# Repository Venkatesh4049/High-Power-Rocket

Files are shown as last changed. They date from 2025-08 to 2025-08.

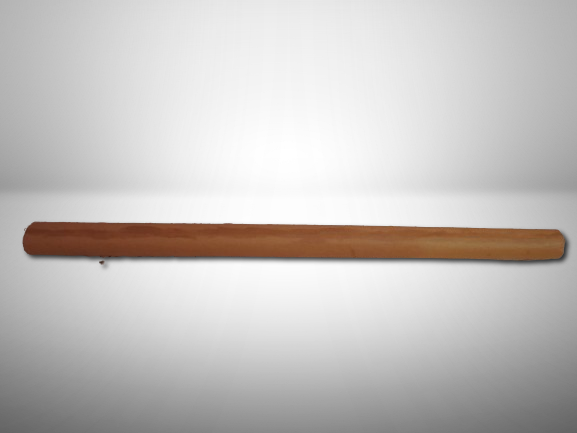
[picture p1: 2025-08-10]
Images/Bodytube.png

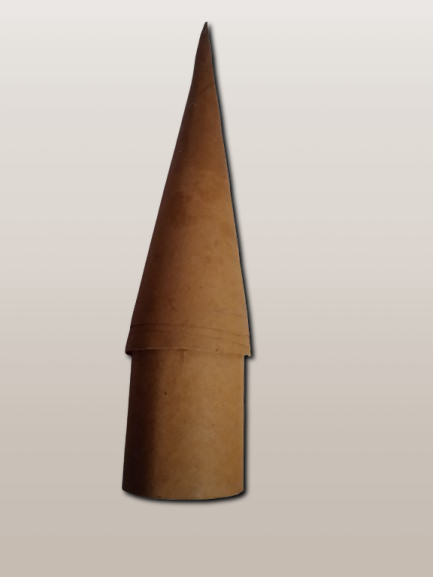
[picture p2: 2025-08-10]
Images/Nose side.png

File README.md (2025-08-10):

# High-Power Rocket Project

**Design and Development of a High-Power Rocket Using Composite Materials**

This repository contains the design, fabrication, and testing details of a student-built high-power rocket made from kraft-phenolic composite materials and powered by a potassium nitrate–glucose solid propellant. The project demonstrates that affordable, sustainable materials can achieve high-performance results in amateur rocketry.

## Features
- Kraft-phenolic composite body, fins, and nose cone for strength, thermal resistance, and low cost
- Custom solid propellant (KNO₃–glucose) with optimized grain geometry
- De Laval nozzle design for efficient thrust
- Parachute recovery system with ejection charge triggered at apogee
- Avionics bay with sensors, telemetry, and data logging
- Aerodynamic and propulsion simulations using OpenRocket and OpenMotor
- Static ground tests and subsystem validation

## Repository Structure
.
├── README.md                 # Project overview  
├── LICENSE                    # License file  
├── High_Power_Rocket.pdf      # Full project report  
├── CAD/                       # 3D models and drawings  
├── Simulations/               # OpenRocket (.ork) and OpenMotor files  
├── Fabrication/               # Build instructions, material specs  
├── Propulsion/                # Propellant design and nozzle calculations  
├── Recovery/                  # Parachute design, ejection system  
├── Electronics/               # Avionics schematics and firmware  
├── Testing/                   # Static tests, flight data  
└── docs/                      # Diagrams, additional documentation  

## Getting Started
1. Clone the repository:
   git clone https://github.com/Venkatesh4049/High-Power-Rocket.git
   cd High-Power-Rocket

2. Open `High_Power_Rocket.pdf` for the complete project documentation.

3. Use OpenRocket and OpenMotor to view simulation files in `/Simulations/`.

4. Explore CAD designs in `/CAD/` and build instructions in `/Fabrication/`.

## Safety & Legal Notice
This project is for educational purposes only.  
Follow all local regulations for propellant handling, motor building, and rocket launches.  
Always use approved testing and launch facilities with appropriate safety measures.

## License
Released under the MIT License. See `LICENSE` for details.

## Credits
Project by Venkatesh A M and team. See `High_Power_Rocket.pdf` for full acknowledgments.

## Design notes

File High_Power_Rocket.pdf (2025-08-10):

# DESIGN AND DEVELOPMENT OF A HIGH-POWER ROCKET USING COMPOSITE MATERIALS

### ME3811 - PROJECT WORK

### Submitted by

VENKATESHA RISHI A 910021114048
VENKATESH A M | 910021114049
SANJAY ROOPAN S | 910021114036
NISANTHALAL M J | 910021114029

### in partial fulfillment for the award of the degree of

# BACHELOR OF ENGINEERING

in

# MECHANICAL ENGINEERING

## ANNA UNIVERSITY, REGIONAL CAMPUS

## MADURAI - 625019

## ANNA UNIVERSITY: CHENNAI 600 025

### MAY 2025

# ANNA UNIVERSITY: CHENNAI - 600025

## BONAFIDE CERTIFICATE

Certified that this project report titled ”DESIGN AND DEVELOPMENT OF A HIGH-

POWER ROCKET USING COMPOSITE MATERIALS” is the bonafide work of VENKATESHA

RISHI A - 910021114048, VENKATESH A M - 910021114049, SANJAY ROOPAN S - 910021114036,

NISANTHALAL M J - 910021114029 who carried out the project under my supervision.

SIGNATURE | SIGNATURE
HEAD OF THE DEPARTMENT | PROJECT SUPERVISOR
Dr.S.Sudhakar | Mr.B.J Ashok Kumar
Assistant Professor | Teaching Fellow
Department of Mechanical Engineering | Department of Mechanical Engineering
Anna University Regional Campus | Anna University Regional Campus
Madurai - 625019 | Madurai - 625019

Submitted for the project viva-voice examination held on

Internal Examiner | External Examiner

i

# ABSTRACT

In a time where space exploration is often confined to billion-dollar agencies and high-end

facilities, this project represents a bold step towards democratizing rocketry through ingenuity, sus-

tainability, and resourcefulness. This study documents the complete design, fabrication, and testing

of a high-power rocket built using kraft paper-based composite materials and a homemade solid pro-

pellant composed of potassium nitrate and glucose. Developed entirely by a small student team with

minimal resources, the rocket was engineered to achieve substantial thrust and structural performance

while remaining environmentally conscious and cost-effective.

Core systems including a custom-made de Laval nozzle, modular payload bay, and a parachute-

based recovery mechanism were integrated using lightweight, low-cost materials without compromis-

ing on reliability. The propulsion system underwent rigorous static ground testing to validate burn

stability, pressure response, and overall mechanical integrity. Furthermore, a simple yet effective elec-

tronics suite was employed to facilitate future implementation of sensing, tracking, and telemetry so-

lutions.

The challenges posed by legal, ethical, and logistical constraints—especially within the Indian

aerospace context were met with caution, innovation, and an unwavering commitment to safe practices.

In doing so, this project not only serves as a proof of concept for affordable, student-led rocket engi-

neering, but also as a powerful inspiration: that space-bound dreams need not wait for billion-dollar

budgets they can ignite from paper, patience, and purpose.

ii

# ACKNOWLEDGEMENT

We take this opportunity to express our deepest gratitude to all those who contributed to the successful completion of this project, both directly and indirectly.

First and foremost, we extend our sincere thanks to our teaching staff and project advisor, Mr.B.J Ashok Kumar, from the Department of Mechanical Engineering, Anna University Regional Campus, Madurai, for his invaluable guidance, continuous support, and constructive feedback throughout every phase of the project. His mentorship was instrumental in helping us transform our initial ideas into a functioning high-power rocket system.

We are equally grateful to our respected Head of the Department, Dr.S.Sudhakar, Department of Mechanical Engineering, for fostering a supportive academic environment and encouraging us to take up such a challenging and ambitious project.

We would also like to express our heartfelt thanks to all the teaching and non-teaching staff of the Mechanical Engineering Department for their assistance and encouragement. Their technical inputs and logistical support were crucial during the various stages of fabrication and testing.

Special thanks are also due to the faculty and lab technicians from other departments, who offered us access to their tools, knowledge, and time whenever we sought interdisciplinary help. Their willingness to collaborate played a vital role in overcoming practical hurdles in electronics integration, testing instrumentation, and material processing.

We would also like to thank our classmates and friends for standing by us through the demanding phases of design, simulation, prototyping, and static testing. Their moral support, collaboration, and occasional hands-on help kept us motivated and focused.Finally, we extend our deepest appreciation to our families for their constant support, patience, and encouragement, without which this journey would not have been possible.

This project was not just an academic venture it was a culmination of teamwork, learning, and perseverance. We are truly grateful to everyone who contributed to this achievement.

VENKATESHA RISHI A VENKATESH A M SANJAY ROOPAN S NISANTHALAL M J
910021114048 | 910021114049 | 910021114036 | 910021114029

iii

# TABLE OF CONTENTS

ABSTRACT | ii
ACKNOWLEDGEMENT | iii
TABLE OF CONTENTS | iv
LIST OF FIGURES | vi
ABBREVIATIONS | vii
1 Introduction | 1
2 Literature Review | 4
3 Objectives | 9
3.2 Development of a Single-Use, Modular KNO3–Glucose Solid Propellant Grain System | 9
4 Functional Requirements | 12
5 Design Approach | 14
6 Mechatronics and Controls | 28

iv

7 Propulsion | 32
8 Methodology | 36
9 Testing Results | 52
10 Challenges | 61
11 Conclusion | 66
References | 67

v

# List of Figures

5.1 Nose Cone Concet model from Blender | 16
5.2 Nose Cone Data from Open Rocket | 17
5.3 Comparison of Four Nose Cone Shapes | 17
5.4 Nose cone comparison | 17
5.5 Fin Concept model from Blender | 18
5.6 Different Fin Designs | 19
5.7 Fin Set data from Open Rocket | 19
5.8 Coupler data from Open Rocket | 20
5.9 First Body data from Open Rocket | 21
5.10 Second Body data from Open Rocket | 21
5.11 Body Concept model from blender | 22
5.12 Body with fins concept model from blender | 23
5.13 Rocket data from open rocket | 24
5.14 Full rocket Concept model from blender | 24
5.15 Nozzle data | 25
5.16 Motor Characteristic | 27
5.17 Motor Characteristic from open motor | 27
7.1 KN calculation | 33
7.2 KN vs Web regression | 34
8.1 Conept Model from blender | 37
8.2 Rocket Art from Blender | 38
8.3 Rocket Concept art from open rocket | 39
8.4 Nose | 40
8.5 Body of the Prototype | 41
8.6 Fins | 43
8.7 Motor along with the nozzle | 44
8.8 Parachute | 48
8.9 Rocket Assembly | 51
9.1 Roll characteristics | 58
9.2 Stability vs Time | 58
9.3 Vertical motion vs Time | 59
10.1 Concept Art 1 | 64
10.2 Concept Art 2 | 65

vi

# ABBREVIATION

KNO3 Potassium Nitrate

KNSU Potassium Nitrate Sucrose

KNSB Potassium Nitrate Sorbitol

BATES Ballistic Test and Evaluation System

NASA National Aeronautics and Space Administration

ISRO Indian Space Research Organisation

GPS | Global Positioning System
CG | Center of Gravity
CP | Center of Pressure

SRAD Student Researched and Developed

IMU | Inertial Measurement Unit
SD | Secure Digital
3FG | Three-Fin Geometry
4FG | Four-Fin Geometry
CO | Carbon Monoxide
PCB | Printed Circuit Board
CAD | Computer-Aided Design

ESP32 Espressif Systems Microcontroller

Wi-Fi Wireless Fidelity

MPU Motion Processing Unit

BMP | Barometric Pressure Sensor
DAQ | Data Acquisition
ESD | Electrostatic Discharge

vii

FFT Fast Fourier Transform

MTCR Missile Technology Control Regime

DGCA Directorate General of Civil Aviation

DRDO Defence Research and Development Organisation

STEM Science, Technology, Engineering, and Mathematics

viii

# CHAPTER 1: Introduction

This project revolves around the design and development of a high-power, single-stage model rocket capable of reaching impressive altitudes approaching 1500 meters, powered entirely by a hand-crafted solid fuel system. The rocket was conceived and constructed from the ground up using an unconventional approach that favored affordability, accessibility, and innovation over industrial-grade materials or commercial components. Central to this project is the use of a kraft phenolic composite material—an inexpensive, lightweight, and surprisingly durable alternative to carbon fiber. This composite offers a significant advantage: while it lacks the extreme tensile strength of carbon fiber, it is easier to work with, more cost-effective for student-led development, and capable of withstanding the thermal and mechanical loads encountered during high-speed flight.

The body of the rocket, including its fins, rings, and structural segments, was hand-fabricated using this kraft phenolic composite, which allowed for fine customization of part geometry and internal fittings. This also made it possible to achieve tight tolerances essential for stability and recovery system integration. The rocket’s design places emphasis on aerodynamic efficiency and structural resilience, featuring a long ogive-shaped nose cone that minimizes drag while maintaining internal volume for avionics and payload.

Unlike conventional model rockets that rely on commercial motors, this project uses a selfformulated solid propellant made from potassium nitrate and glucose. This sugar-based fuel, sometimes referred to as ”rocket candy,” was selected for its relatively simple preparation process, high energy output, and ease of shaping into modular fuel grains. One of the most unique aspects of this design is the inclusion of a replaceable fuel canister system, which allows for rapid reloading and experimentation with different grain geometries and burn profiles. This modularity in the propulsion system makes it ideal for educational purposes, enabling repeated ground testing and gradual performance optimization.

The propulsion system was carefully designed to be compatible with the recovery mechanism. The internal pressure build-up from combustion is utilized to trigger the ejection of a dual-stage recovery system, consisting of a shock-cord-linked payload bay, a drogue chute, and a main parachute. This integration ensures that the recovery sequence is synchronized with apogee, thereby reducing landing speed and minimizing structural damage. Every aspect of the rocket—from the fin geometry and coupler placement to the mass distribution and thrust-to-weight ratio—was simulated using OpenRocket. These simulations helped validate design decisions and refine stability margins, taking into account the unique burn characteristics of the hand-made propellant.

Through this project, we explored an approach that relies less on expensive aerospace-grade materials and more on fundamental principles of aerodynamics, chemistry, and mechanical design. The result is a high-power rocket system that is robust, modular, and built almost entirely with hand-crafted components. In an academic environment where access to advanced manufacturing equipment is limited, this project demonstrates that intelligent material selection, careful design, and iterative testing can produce a vehicle that rivals more expensive alternatives in performance, while remaining entirely student-built and ground tested.

## 1.1 Problem Definition

The central problem addressed by this project is how to design, fabricate, and successfully launch a high-power model rocket using non-conventional, low-cost materials without compromising structural integrity, flight performance, or safety. Traditional model rockets often rely on precisionmanufactured components and aerospace-grade materials such as fiberglass, carbon composites, or aluminum alloys. These are expensive, require specialized equipment to work with, and are often inaccessible in a university setting without significant financial backing. In contrast, our team has chosen to develop the rocket using a kraft-paper-like laminated fiber-cellulose composite—a material more commonly associated with packaging—aiming to push the boundaries of what such materials can achieve in aerospace applications.

The problem extends far beyond just selecting a cheap material. A rocket undergoes extreme mechanical and thermal stress during its operation. From the moment of ignition, the propulsion system produces rapid accelerations, heat, and vibration. These factors place tremendous strain on the rocket’s body, joints, and components. The material used must not only withstand these forces but also maintain dimensional stability so that the rocket remains aerodynamically stable throughout the flight. Using a fiber-based composite introduces risks such as delamination, moisture absorption, and buckling under pressure—all of which had to be accounted for through intelligent design choices, reinforcement strategies, and rigorous testing.

Furthermore, the rocket is required to carry a payload—potentially for atmospheric sensing or data collection—requiring the design to accommodate a modular payload bay. This adds additional weight and complexity, especially in a structure that is already pushing the limits of its material strength. Simultaneously, the rocket must also incorporate a reliable recovery mechanism. Without it, the risk of crash-landing increases, which could damage the rocket beyond reuse or pose a safety hazard. The inclusion of a parachute-based deployment system adds yet another layer of engineering complexity, particularly when dealing with passive triggers or small ejection charges that must activate at a specific point in the flight.

Designing the rocket is not a matter of assembling separate parts in isolation; each component directly affects others. For example, the dimensions and shape of the nose cone influence drag and therefore affect the size and placement of fins needed for stability. These, in turn, shift the rocket’s center of pressure, which must always remain behind the center of gravity to ensure stable flight. These relationships forced us to adopt an iterative design process, where changes in one part necessitated recalculations and often physical redesigns of other components. The material’s behavior, especially under load, introduced further complications, as real-world performance sometimes deviated from analytical predictions. Adding to these challenges was the decision to fabricate all major components in-house. Unlike some academic programs that outsource parts to professional suppliers, we intentionally chose a hands-on approach to deepen our understanding of each step in the development process. This decision meant building the nose cone, fins, motor casing, and avionics bay ourselves, using only basic tools and workshop equipment. As a result, the team faced steep learning curves in terms of precision fabrication, curing of composites, and maintaining symmetry in rotating parts.

In essence, this project takes on a multi-faceted engineering challenge: to deliver a functioning, high-power rocket made from an unorthodox material, designed and constructed entirely by undergraduate students, and capable of performing a real-world test flight with recoverability and payload compatibility. The problem, therefore, is not just technical—it is logistical, educational, and experimental in nature. It tests our ability to translate theoretical knowledge into a functioning aerospace system under material, financial, and time constraints.

# CHAPTER 2: Literature Review

## 2.1 Model Rocketry with Sugar-Based Propellants

Sugar-based solid propellants, often referred to as “candy propellants,” are widely used in the experimental and amateur rocketry community due to their affordability, availability, and relatively safe handling characteristics. The most common formulation involves a mixture of potassium nitrate (KNO3) as the oxidizer and a sugar (such as sucrose, dextrose, or glucose) as the fuel. This combination is known as KNSU (potassium nitrate–sucrose) or more generally KNSB when variations like glucose are used. The glucose-based version was chosen for our project due to its lower melting point and easier handling during the casting process.

The works of Richard Nakka, a pioneer in sugar-propellant research, laid the foundation for understanding how different ratios, casting techniques, and grain geometries affect burn performance and internal chamber pressures. His tests showed that sugar propellants, when properly processed, can generate enough thrust to reach several kilometers in altitude, rivaling low-end commercial motors. This performance, coupled with low toxicity and the absence of specialized manufacturing requirements, makes sugar propellants especially attractive for academic and hobbyist rocket projects.

Further experimentation by online research communities and academic groups (such as those documented on forums like The Rocketry Forum and in publications from amateur engineering projects) has refined grain designs like BATES, core-burn, and end-burn configurations. These studies emphasize burn rate control, structural containment, and nozzle efficiency—all critical to prevent overpressurization and ensure consistent thrust.

Our own propulsion system draws directly from this body of research. We selected a glucose-KNO3 mixture, hand-cast into a phenolic composite casing. The cylindrical grain design and nozzle were optimized through OpenMotor simulation, ensuring compatibility with the body tube and predicted apogee. Unlike commercial motors, this hand-crafted propellant system is tailored to match our custom-made ejection system and recovery compartment, allowing for full mission flexibility without dependency on commercially rated thrust or delay timings.

This body of literature firmly supports the practicality of using sugar propellants for high-performance, low-cost rocketry, especially when paired with simulation tools and modular design practices like ours.

## 2.2 Kraft-Based and Phenolic Composite Structures in Rocketry

The use of kraft-based and phenolic composites in rocket structural components represents an innovative approach, particularly in the context of cost-effectiveness and manufacturing simplicity. Unlike traditional materials such as carbon fiber composites, fiberglass, or metals like aluminum and titanium, kraft phenolic composites offer a unique balance of mechanical strength, thermal resistance, and affordability.

Phenolic resins are well-known for their excellent heat resistance and low flammability, properties essential for components exposed to high thermal loads during rocket launches. When combined with kraft paper, a natural cellulose fiber, these composites provide sufficient structural integrity for medium to high-power rocketry applications without the high cost and complex fabrication techniques demanded by carbon fiber or metal alloys.

One key advantage of kraft phenolic composites is their environmental friendliness and ease of handling. Kraft paper is a renewable resource, and its integration into phenolic resin matrices reduces reliance on petroleum-based synthetic fibers. This translates into a more sustainable manufacturing process with lower embodied energy compared to carbon fiber production, which is energy-intensive and expensive.

NASA’s research into phenolic composites has historically validated their use in heat shields, ablative coatings, and structural parts of spacecraft and sounding rockets. The material’s ability to maintain strength at elevated temperatures, resist chemical degradation, and provide good mechanical stiffness has made phenolic composites a go-to choice in certain aerospace applications. While NASA predominantly uses high-performance carbon composites for critical load-bearing parts, phenolicbased composites are often employed for thermal protection systems and components where cost and thermal stability are prioritized over ultra-high strength.

In our project, using kraft phenolic composites for the rocket’s body tubes, nose cone, and fins was a strategic decision driven by these proven advantages. Compared to carbon fiber, our chosen material provides sufficient strength and stiffness for the intended flight envelope, better thermal tolerance during motor ignition, and significantly reduced costs. Moreover, the ease of fabrication through epoxy impregnation and curing enables rapid prototyping and repair, essential for a student-led experimental program.

Thus, this composite structure aligns well with the goals of producing a reliable, cost-effective, and sustainable rocket, with credible precedents in aerospace research and practical field use.

## 2.3 Recovery Systems in High-Power Amateur Rockets

Recovery systems play a crucial role in the design and operation of high-power amateur rockets, serving as the primary means to ensure the safe return of the rocket and its valuable components after flight. Unlike smaller model rockets, high-power rockets reach greater altitudes and velocities, which significantly increases the risk of damage upon landing if proper recovery methods are not employed. Consequently, the development and optimization of effective recovery systems have been a focal point of amateur rocketry research and practice.

The most common recovery mechanism involves the deployment of parachutes, which slow the rocket’s descent by increasing drag and reducing terminal velocity to a non-destructive level. Typically, multi-stage recovery systems are used to manage different phases of descent. For instance, a drogue parachute may be deployed immediately after the rocket reaches apogee to stabilize and slow it during the initial, faster descent phase. Following this, a larger main parachute is deployed at a lower altitude to further reduce descent speed, ensuring a gentle touchdown.

The design and timing of these deployments are critical. Deployment must occur at precise moments to avoid damage to the rocket structure or payload and to prevent premature opening that could destabilize the rocket during ascent. Advanced electronics such as altimeters, barometric sensors, or accelerometers are often integrated to detect apogee and trigger ejection charges that deploy parachutes. These electronics are carefully selected and tested to withstand the dynamic flight environment, including acceleration, vibration, and thermal conditions.

The materials chosen for parachutes and recovery components also impact the effectiveness and reliability of the recovery system. Ripstop nylon is widely favored due to its high strength-to-weight ratio, durability, and resistance to tearing. The use of braided nylon or Kevlar cords for shroud lines ensures secure attachment between the parachute canopy and rocket body, with minimal risk of line failure during deployment stresses.

In recent years, amateur rocketry enthusiasts and organizations such as the National Association of Rocketry (NAR) and Tripoli Rocketry Association have published extensive guidelines and best practices to improve recovery system designs. These include recommendations for parachute sizing based on rocket mass and descent velocity, shock cord specifications, and ejection charge calculations. The development of reliable recovery systems not only protects physical assets but also promotes safety in rocketry activities, reducing hazards to people and property near launch sites.

Furthermore, innovations have emerged in recovery technologies, such as the use of dual-deployment systems where both drogue and main parachutes are employed, GPS tracking devices for easier rocket retrieval, and telemetry systems that transmit live flight data including altitude and velocity. These advancements reflect an ongoing effort to enhance the efficiency, safety, and reusability of high-power rockets.

In this project, the recovery system design incorporates these principles by employing a ripstop nylon parachute with appropriately sized shroud lines, integrated with an ejection system that synchronizes with the solid fuel motor’s burn profile and apogee detection. This ensures that the rocket descends safely at a controlled velocity, maximizing the potential for reuse and minimizing risk. The compatibility of the recovery system with the propulsion and structural components was a critical design consideration, ensuring seamless integration and operational reliability.

## 2.4 Simulation Tools and Performance Prediction

The design and development of high-power rockets heavily rely on accurate simulation tools to predict flight performance and ensure structural integrity prior to fabrication and launch. In this project, OpenRocket and Open Motors were the primary simulation platforms used to guide the design process, validate choices, and optimize performance parameters.

OpenRocket is an open-source model rocket simulation software widely used in amateur and educational rocketry projects. It allows for comprehensive aerodynamic modeling, trajectory prediction, and stability analysis of rocket designs. The software integrates essential physical parameters such as drag coefficients, center of gravity (CG), center of pressure (CP), motor thrust curves, and mass distribution to simulate flight behavior under various atmospheric conditions. Its ability to quickly iterate different design variants made it an invaluable tool in this project, especially considering the evolving design requirements and the need to balance aerodynamic efficiency with structural constraints.

OpenRocket’s aerodynamic calculations use a combination of empirical methods and analytical models, such as Barrowman equations for stability and drag predictions, which have been validated by multiple experimental studies. For instance, the Barrowman method is recognized in literature (Barrowman, 1967) for providing reliable estimates of rocket stability and aerodynamic forces, which align well with real flight data when used within its validity range.

Complementing OpenRocket, Open Motors served as the propulsion simulation tool, providing detailed thrust profiles and impulse calculations for the motor selection. Open Motors offers access to a database of commercial and custom rocket motors with associated thrust-time curves, enabling accurate prediction of acceleration, velocity, and altitude. This data was critical in matching the propulsion capabilities with the structural and aerodynamic design to meet the mission requirements.

Several studies highlight the effectiveness of combining these tools in amateur rocketry projects. According to research by Anderson et al. (2018), the integration of simulation platforms like Open-Rocket and motor thrust analysis tools significantly reduces design iteration cycles, improves flight prediction accuracy, and enhances safety margins. Furthermore, the ability to model different motor configurations and simulate multiple separation events within OpenRocket allowed the project team to refine recovery systems and staging concepts early in the design phase.

The use of these simulation tools also facilitated sensitivity analyses on key design variables such as fin size, nosecone shape, and motor thrust, which helped identify optimal configurations to maximize altitude and stability. Given the limitations of physical prototyping resources, these digital tools provided a cost-effective and low-risk environment to validate design decisions before committing to fabrication.

OpenRocket and Open Motors played a crucial role in this project’s design cycle, enabling informed decision-making based on reliable performance predictions. Their use reflects a growing trend in amateur and educational rocketry to adopt accessible, validated simulation software to bridge theoretical design and practical application, thereby increasing the success rates of high-power rocket launches.

During the design and development of this high-power rocket, various software tools and expert resources played a crucial role in ensuring the accuracy, efficiency, and success of the project. SolidWorks was chosen as the primary CAD software due to its robust parametric modeling capabilities and engineering precision. It allowed us to build detailed 3D models of the rocket’s structural components, simulate assembly, and perform preliminary interference checks. This step was essential for visualizing complex geometries and refining design dimensions before physical fabrication, thus minimizing costly errors.

To complement the technical CAD models, Blender was utilized to enhance the aesthetic and conceptual aspects of the rocket design. Blender’s advanced sculpting, texturing, and rendering features enabled us to create high-fidelity visualizations and animations. This artistic approach provided a better understanding of the rocket’s form and appearance, which is valuable for presentations, stakeholder communication, and overall design validation.

In addition to these software tools, Richard Nakka’s Experimental Rocketry Web Site served as an indispensable knowledge base throughout the project. This website offers comprehensive insights into solid rocket motor design, including propellant chemistry, grain geometry, nozzle optimization, and static test analysis. Leveraging this resource helped us ground our theoretical calculations in practical experience and guided our approach to propulsion design and static testing. The detailed data and experimental results presented by Richard Nakka allowed us to benchmark our results and improve the reliability of our rocket motor’s performance predictions.

Together, these tools and resources formed a critical backbone of our workflow, bridging the gap between theoretical design, practical fabrication, and visual conceptualization, thereby enhancing both the technical and creative dimensions of our project.

# CHAPTER 3: Objectives

## 3.1 Development of a High-Altitude Rocket Using Kraft Phenolic

## Composite

The primary objective of this project is to design and build a sounding rocket capable of reaching an altitude of approximately 1,000 meters (1 kilometer). Achieving this target altitude requires an integrated approach that balances aerodynamic efficiency, structural integrity, and propulsion performance. A critical focus of the design is the use of kraft phenolic composite material for the rocket’s structural components. This material was chosen due to its advantageous properties such as high strength-to-weight ratio, thermal resistance, and cost-effectiveness compared to conventional aerospace materials like carbon fiber or metallic alloys.

By utilizing kraft phenolic composite, the project aims to demonstrate that high-performance rocket structures can be fabricated using more accessible, sustainable materials without compromising reliability. The composite’s favorable mechanical characteristics are expected to provide adequate stiffness and durability under the dynamic loads experienced during launch, ascent, and recovery. Additionally, the material’s thermal stability will help withstand the heat generated by the solid fuel motor and aerodynamic heating during flight.

The design objective extends beyond structural considerations to encompass the integration of a solid fuel propulsion system made from a homemade potassium nitrate and glucose propellant. This fuels system must be compatible with the overall rocket design, ensuring stable thrust generation and reliable motor casing integration within the composite airframe. Moreover, the rocket will incorporate a functional recovery system with an ejection mechanism to deploy parachutes at apogee, safeguarding the vehicle for potential reuse and minimizing impact damage.

This objective encapsulates the development of a prototype that not only meets altitude and stability requirements but also validates the practical application of kraft phenolic composites in amateur and educational rocketry. Ultimately, this project seeks to contribute to the knowledge base on alternative composite materials in rocketry and establish a replicable process for building reliable, cost-efficient high-power rockets.

## 3.2 Development of a Single-Use, Modular KNO3–Glucose Solid

## Propellant Grain System

The objective of this phase is to design and implement a modular solid-fuel propulsion system using a KNO3–glucose mixture as the working propellant. While the module is designed for single-use, its construction follows a modular approach—allowing the entire fuel assembly to be prepared, integrated, and later replaced as one complete unit. This balances the practical need for reusability in structure with the chemical and safety limitations of solid propellant-based systems.

The KNO3–glucose composition is selected for its proven reliability in amateur rocketry. It offers a stable burn profile, relatively low combustion temperature compared to composite propellants, and is manufacturable with accessible equipment and materials. The grain is cast or pressed into a pre-defined cavity—usually cylindrical with a central core—to control surface area and burn duration.

The modularity lies in how the fuel grain, nozzle, and containment structure are fabricated as a single, pre-packaged unit. This unit is inserted into the rocket during assembly and fully removed post-launch, making way for a freshly prepared module. Although the fuel itself is not reusable, this method significantly simplifies ground preparation and increases consistency between launches.

Additionally, this system is engineered to be compatible with the rocket’s ejection system. The burn duration and thrust curve are matched with the required apogee timing and delay settings, ensuring the recovery sequence is initiated correctly. By integrating the propellant design into the broader mission architecture, this objective enhances overall mission reliability, while maintaining flexibility for future upgrades or changes to the grain design.

## 3.3 Integration of an Ejection-Based Recovery and Payload De-

## ployment System

One of the key objectives of this project is to design a reliable, self-contained recovery system that activates upon the complete burnout of the solid fuel charge. The rocket employs a delay and ejection charge mechanism, integrated directly into the fuel casket module, to initiate recovery procedures without the need for external electronics or separate triggering mechanisms.

This system operates on a simple yet effective principle. After the main KNO3–glucose propellant completes its burn, a pre-packed delay composition continues to burn for a predetermined period—calculated based on the rocket’s expected time to apogee using simulation tools like Open-Rocket. Following the delay, the combustion of the ejection charge rapidly builds pressure within the motor casing, forcing out the nose cone.

Attached to the nose cone is one end of a ripstop nylon parachute, while the other end remains tethered to the main body using a high-strength elastic shock cord. This ensures that the parachute unfurls cleanly and stabilizes the rocket for descent. The force of the ejection is calibrated precisely to eject the nose and deploy the parachute without causing damage to the structure.

In addition to stabilizing the descent, this system is also designed to deploy any onboard payloads housed in the forward section of the rocket. The payload bay is located just beneath the nose cone, and the ejection sequence ensures both the payload and the recovery system are released simultaneously in a controlled manner.

This method reduces the complexity and cost typically associated with electronic deployment systems, while still achieving timely, altitude-appropriate deployment. By tightly integrating the ejection system with the propellant module, the recovery process remains synchronized with the flight dynamics, improving safety, reusability of the main structure, and mission success rate.

## 3.4 Validate Performance Through Simulation and Ground Test-

## ing

To ensure the rocket performs reliably and meets its design goals, its flight characteristics and subsystems are validated through both digital simulation and physical ground testing. The first step in this validation process involves using OpenRocket, an open-source rocketry simulation tool. This software allows for detailed modeling of the rocket, including its geometry, mass distribution, propulsion profile, and recovery system. By entering accurate parameters such as the center of gravity, center of pressure, thrust curves, and aerodynamic profiles, OpenRocket can simulate the entire flight sequence—from launch to recovery.

The simulations provide critical data, including predicted altitude, velocity at liftoff and apogee, time to apogee, stability margins, and the optimum delay for deploying the recovery system. These insights help in making iterative design adjustments early, without wasting physical resources.

However, simulations alone aren’t sufficient. After achieving satisfactory digital results, physical ground testing is performed to validate those predictions in the real world. Static burn tests of the KNO3–glucose propellant help assess burn time, thrust, and structural behavior under pressure. Similarly, recovery deployment tests are carried out to verify whether the parachute and ejection mechanisms function as intended—especially since the ejection charge is integrated into the fuel casket. These tests also ensure the shock cord and nose-cone ejection mechanics can withstand operational stresses. By combining simulation and ground testing, the project ensures that theoretical expectations are reinforced with real-world validation, reducing the risk of failure during actual flight and improving confidence in the rocket’s performance envelope.

# CHAPTER 4: Functional Requirements

The rocket designed for this project must fulfill several critical functional requirements to ensure a successful and safe flight mission. The primary objective is for the rocket to reach an approximate target altitude of 1 kilometer (about 3,280 feet) while maintaining stable, controlled flight throughout its ascent and descent phases. All subsystems—structural, mechatronic, recovery, and propulsion—must operate reliably and in harmony to achieve this goal within the constraints of low-cost construction and limited institutional resources. From a structural standpoint, the rocket must endure the mechanical loads generated during motor ignition, takeoff, and the entire duration of flight. The frame, built using a laminated fiber-composite material based on kraft paper, must maintain its structural integrity under axial thrust, aerodynamic drag, and vibrational forces without significant deformation or failure. The design also mandates two separation events during flight: the first at apogee for payload deployment, and the second for parachute release. These separations must be mechanically robust and precisely timed to avoid premature ejection or structural damage.

The mechatronics subsystem plays a pivotal role in the autonomy and intelligence of the rocket. It must accurately detect the moment of apogee—the highest point in the rocket’s flight trajectory—and trigger the deployment mechanisms accordingly. Furthermore, the onboard electronics are expected to collect and transmit live telemetry data back to a ground station in real time, providing insight into parameters such as altitude, velocity, acceleration, orientation, and system health. This data is vital not only for performance evaluation but also for triggering critical events in-flight. The payload deployment system is required to function precisely at apogee. Its success is contingent on both the mechanical reliability of the deployment mechanism and the accuracy of the sensor readings used to determine flight position. A failure in this sequence could result in the payload being damaged or lost, defeating one of the mission’s core objectives.

For safe recovery, the rocket must deploy a parachute at a point in the descent phase that allows sufficient time for full inflation and controlled deceleration. The descent velocity must be kept within a range that avoids structural damage upon landing, allowing for inspection, possible reuse, and post-flight data retrieval. Timing, altitude, and orientation at the moment of deployment are all critical factors to be accounted for in the parachute system design. Lastly, the propulsion system must be powerful enough to carry the combined mass of the rocket and payload to the desired altitude. The motor and its housing must withstand the thermal and mechanical stresses generated during combustion. Since the rocket is intended to reach approximately 1 km, the thrust must be calibrated to achieve this target with acceptable margin while ensuring that acceleration does not destabilize the structure or compromise component integrity. The propellant choice, burn rate, and thrust profile must align with the aerodynamic characteristics of the overall design to deliver predictable and safe performance.

In summary, each subsystem of the rocket must satisfy its individual performance criteria while integrating seamlessly into the larger framework. The collective goal is a coordinated, successful flight reaching approximately 1 km altitude, demonstrating that even unconventional, low-cost materials can deliver high-performance aerospace results when paired with thoughtful engineering and robust design practices.

# CHAPTER 5: Design Approach

The design methodology adopted in this project was highly iterative and adaptive, shaped by the unique constraints and the novelty of the undertaking within our academic environment. Given that this was among the first high-power rocketry projects initiated at Anna University Regional Campus, Madurai, there was no established legacy or design precedent to follow. Consequently, we began from first principles, leveraging simulation tools such as OpenRocket for aerodynamic modeling and OpenMotor for propulsion estimation and motor behavior prediction.

Our goal was to engineer a structurally sound rocket composed of a low-cost kraft-paper-based composite material (hereafter referred to as cellulose-reinforced laminate) that could reach approximately 1,000 meters in altitude. From the outset, we prioritized simplicity in design to allow for quick iterations and easy integration of changes during development. OpenRocket enabled us to rapidly evaluate various design configurations, allowing us to refine aerodynamic features such as the nose cone profile, fin placement, and center-of-mass/stability margin with each version. The real-time visual and numerical feedback from the software helped reduce trial-and-error in physical prototyping.

One of the primary aspects of our approach was the integration of a dual-deployment mechanism. We structured the rocket to perform two separation events: one at apogee for the deployment of a drogue parachute and payload, and another during descent to deploy the main parachute. These events were synchronized with onboard sensors capable of detecting flight events, and the timing was fine-tuned using software simulations before hardware fabrication.

The payload bay design evolved through several revisions as we evaluated different positions relative to the avionics bay and main body. Initial iterations, which considered locating the payload aft of the electronics bay, proved problematic due to interference with clean deployment. Later models addressed these issues by relocating and redesigning the payload interface for reliable operation.

σhoop =

P r
t
(Hoop Stress) | (5.1)

Another vital component of our methodology was the thermal assessment of the propulsion system. Initially, we explored the idea of developing a student-researched and designed propulsion unit (SRAD). However, due to the complexities and safety concerns of propellant synthesis—especially given our limited facilities and regulatory constraints—we opted for a commercial off-the-shelf motor. OpenMotor was employed to simulate motor burn characteristics and verify that the selected motor could safely operate within the thermal tolerance limits of our composite body material. We also ensured that any thermal energy dissipated during burn did not compromise the structural integrity of the cellulose-reinforced laminate. Given the constraints in scheduling and access to advanced fabrication tools, our team prioritized modularity in assembly. Each rocket component—fins, body tube, avionics bay, and nose cone—was designed to be individually testable and replaceable. This modular design approach allowed us to proceed with testing even when certain parts were delayed due to material availability or machining schedules.

σlong =

P r
2t
(Longitudinal Stress) | (5.2)

We did not set full-scale launch as an initial success metric. Instead, we defined the successful outcome of the project as the completion of a functional prototype along with verified ground-level subsystem tests. Tests included recovery system activation, structural load tests, and electronic signal verification. These formed the foundation for future iterative improvements and gave us confidence that a full-scale launch would be achievable in subsequent project phases or by future student teams.

σb =

My
I
(Bending Stress) | (5.3)

σv =

q
σ

2
x − σxσy + σ

2
y + 3τ

2
xy | (Von Mises Stress) | (5.4)

The design journey was not without risks. Dependencies between subsystems occasionally caused bottlenecks, particularly when design finalization of one component hinged on the completion of another. Additionally, due to our reliance on workshop facilities for manufacturing, delays in training and access often impacted our timeline. These were mitigated through parallel tasking, improved documentation, and maintaining multiple design options in simulation until fabrication could be initiated.
FOS =

σyield

σmax

(Factor of Safety) | (5.5)

By combining structured simulation-based analysis with hands-on fabrication planning, our design approach provided a realistic pathway for realizing a student-led high-power rocket capable of reaching significant altitudes using sustainable, cost-effective materials.

## 5.1 Aerodynamics and Structures

The aerodynamic and structural design of the rocket plays a vital role in achieving stable and efficient flight. Each component was selected and engineered to balance performance, manufacturability, and structural integrity while adhering to the constraints of available materials and fabrication techniques. Computational simulations and prior references were used to optimize the shape, weight, and placement of components to ensure minimized drag, sufficient stability, and controlled descent.

Static Margin =

CP − CG
D
| (in calibers) | (5.6)

Fd =

1
2
ρV ²CdA | (Drag Force) | (5.7)

Re =

ρV L µ | (Reynolds Number) | (5.8)

### 5.1.1 Nose Cone

The nose cone serves as the foremost aerodynamic structure of the rocket and plays a critical role in minimizing drag during ascent. In early stages of the design, various nose cone geometries such as conical, hemispherical, and parabolic were evaluated using OpenRocket simulations to analyze their impact on aerodynamic performance. While hemispherical cones offer better internal volume and are often used in low-speed model rockets, they produce significantly more drag. Conical shapes are easier to fabricate and provide moderate drag reduction, but are not optimal for higher-speed applications. Parabolic cones offer the least drag at transonic speeds but are complex to model and manufacture.

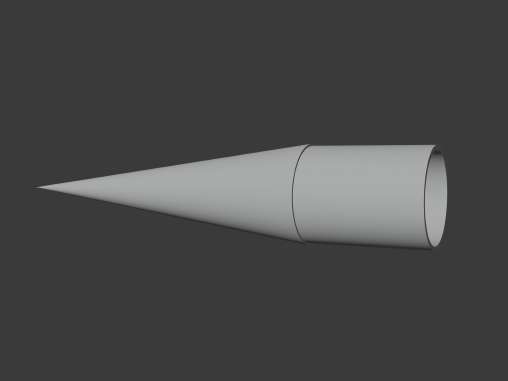
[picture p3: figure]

Figure 5.1: Nose Cone Concet model from Blender

Ultimately, the long conical shape was selected due to its favorable drag characteristics and structural compatibility with the body tube and coupler assembly. Simulations run in OpenRocket showed that the ogive profile maintained stability across various flight conditions, especially under the thrust profile expected from the custom potassium nitrate-glucose based solid fuel. The smooth curvature of the ogive cone facilitates a streamlined airflow, significantly reducing form drag as the rocket climbs through the atmosphere.

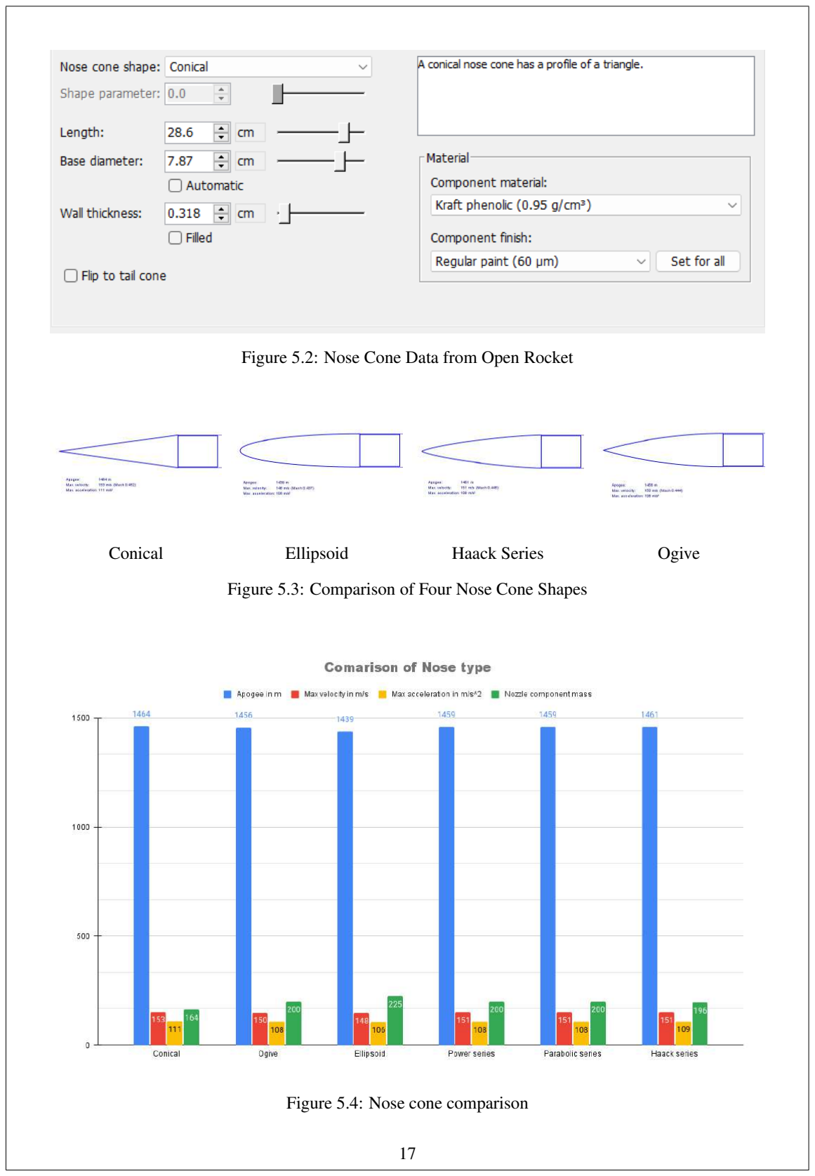
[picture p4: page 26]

Figure 5.2: Nose Cone Data from Open Rocket

Conical | Ellipsoid | Haack Series | Ogive

Figure 5.3: Comparison of Four Nose Cone Shapes

Figure 5.4: Nose cone comparison

The selected nose cone has a length of 28.6 cm and is fabricated from kraft phenolic composite for its light weight and structural integrity. The design process focused heavily on compatibility; the nose cone integrates seamlessly with the kraft phenolic body tube using an internal coupler system. This structural continuity ensures the overall rocket maintains aerodynamic efficiency while also being simple to assemble and disassemble for payload access or recovery system installation.

### 5.1.2 Fins

For the aerodynamic stabilization of the rocket during flight, a set of four clipped delta fins was selected and integrated into the design. The decision followed a detailed examination of existing fin configurations commonly used in high-power amateur and student rocketry, particularly those suitable for subsonic to low-supersonic velocities. Studies consistently highlighted the clipped delta shape as an optimal choice for balancing drag reduction, structural strength, and ease of fabrication. The clipped

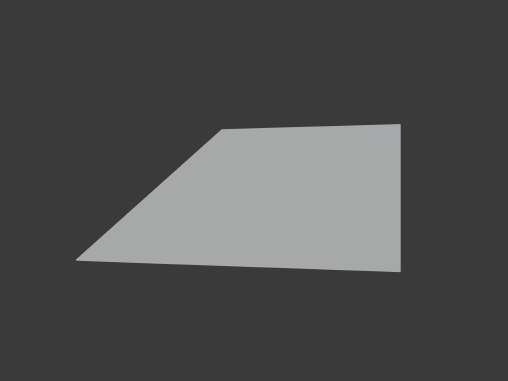
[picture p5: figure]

Figure 5.5: Fin Concept model from Blender

delta fin design, which combines the performance advantages of swept delta fins with reduced base drag, was particularly well-suited for our flight profile. Our simulations in OpenRocket confirmed that the configuration ensured the center of pressure remained at a stable distance behind the center of gravity—approximately 7 cm aft, giving a static margin of 0.806 calibers (or 4.24% of the body diameter), which maintained stable flight without being excessively overstable.

The trapezoidal airfoil profile was selected to simplify manufacturing and ensure consistent bonding to the kraft phenolic composite airframe. This airfoil form offers modest aerodynamic performance while remaining forgiving in terms of alignment and fabrication tolerances. The material used for the fins is the same kraft phenolic composite as the body tube, providing a consistent structural behavior under thermal and mechanical loads during flight. Each fin is permanently bonded to the airframe using high-strength epoxy. While detachable fins were considered during early design phases, they were ultimately set aside in favor of permanence for increased reliability and lower structural complexity. This approach was also advised by experienced mentors, especially given the use of a homemade propulsion system.

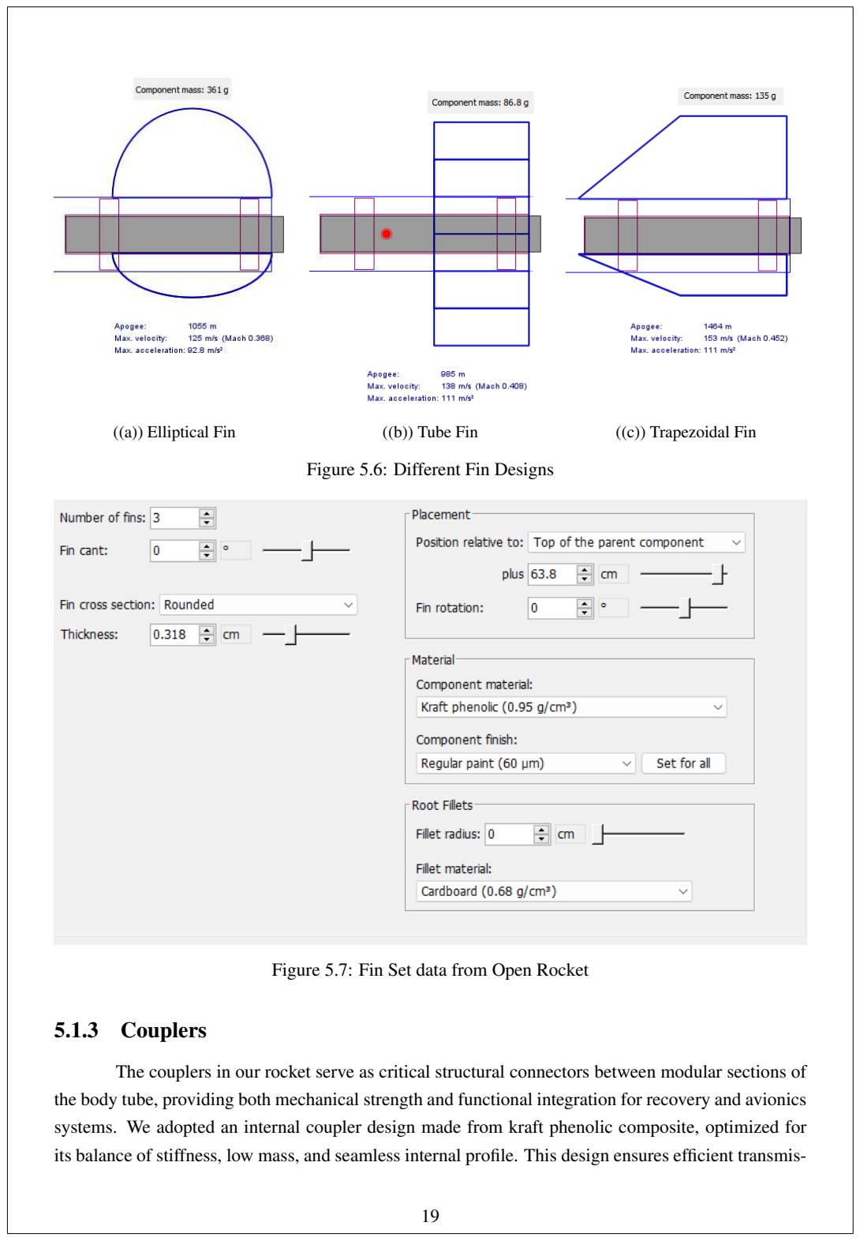
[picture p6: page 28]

((a)) Elliptical Fin | ((b)) Tube Fin | ((c)) Trapezoidal Fin

Figure 5.6: Different Fin Designs

Figure 5.7: Fin Set data from Open Rocket

### 5.1.3 Couplers

The couplers in our rocket serve as critical structural connectors between modular sections of the body tube, providing both mechanical strength and functional integration for recovery and avionics systems. We adopted an internal coupler design made from kraft phenolic composite, optimized for its balance of stiffness, low mass, and seamless internal profile. This design ensures efficient transmission of aerodynamic and inertial loads while preserving the interior space for components such as the ejection charge, parachute rigging, and electronics bay.

Each coupler is designed with an extended shoulder length of approximately one body diameter (15.67 cm), which enhances axial alignment and increases joint stiffness—particularly useful during high-speed ascent and recovery deployment phases. The fit between the coupler and body tube was finely tuned to achieve a snug, interference-free connection, eliminating the need for mechanical fasteners such as shear pins. This allowed us to retain clean internal aerodynamics and reduce stress concentrations typically caused by traditional hardware. The main avionics coupler also functions as

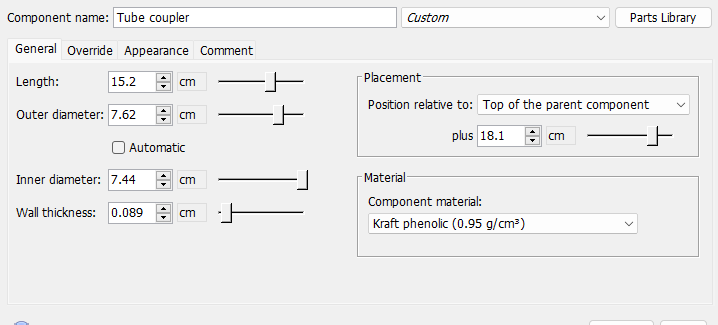
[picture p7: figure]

Figure 5.8: Coupler data from Open Rocket

a deployment joint for the recovery system, utilizing a custom-fitted ejection charge cavity integrated directly into the fuel casket. This design uses the pressure pulse from the KNO3–glucose solid propellant’s end-burn phase to push the nose cone and eject the parachute in a reliable and consistent manner. The coupler system was validated through ground-fit testing and simulations to ensure that it can withstand both the longitudinal and hoop stresses without deformation or failure.

By using kraft phenolic instead of fiberglass or metallic materials, the coupler maintains excellent strength-to-weight characteristics while remaining thermally stable, easy to bond with epoxy, and cost-effective for amateur rocketry. Additionally, its compatibility with RF signals enables future integration of onboard telemetry systems without the need for external antennas.

### 5.1.4 Body

The body of the rocket forms its primary structural framework, enclosing and supporting all critical internal systems including the propulsion module, recovery mechanism, and any onboard payload. Designed to endure aerodynamic loads, motor-induced stresses, and recovery-phase shock, the body must balance mechanical strength with minimal mass. For this reason, kraft phenolic composite—reinforced with an epoxy matrix—was selected as the material of construction. With a density of approximately 0.95 g/cm³, this material offers a favorable strength-to-weight ratio, ease of manufacturing, and better reparability compared to conventional options like carbon fiber, which, while lighter in some configurations, involves greater cost and complexity in fabrication.

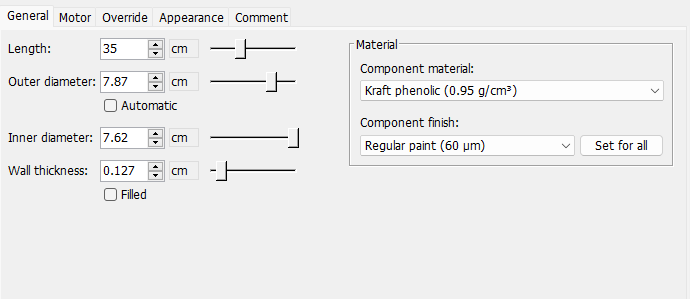
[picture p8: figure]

Figure 5.9: First Body data from Open Rocket

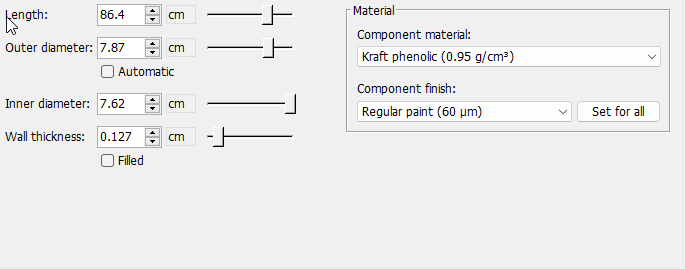
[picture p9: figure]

Figure 5.10: Second Body data from Open Rocket

The structural configuration comprises two cylindrical segments: one measuring 80 cm in length for housing the propulsion system, and another 75 cm in length designated for the recovery assembly and payload integration. Both segments share a uniform outer diameter of 15.67 cm and an inner diameter of 14.8 cm, ensuring seamless integration with couplers and internal bulkheads. These dimensions were finalized through iterative modeling and stability analysis in OpenRocket, taking into account the position of the center of gravity and center of pressure to ensure stable subsonic flight.

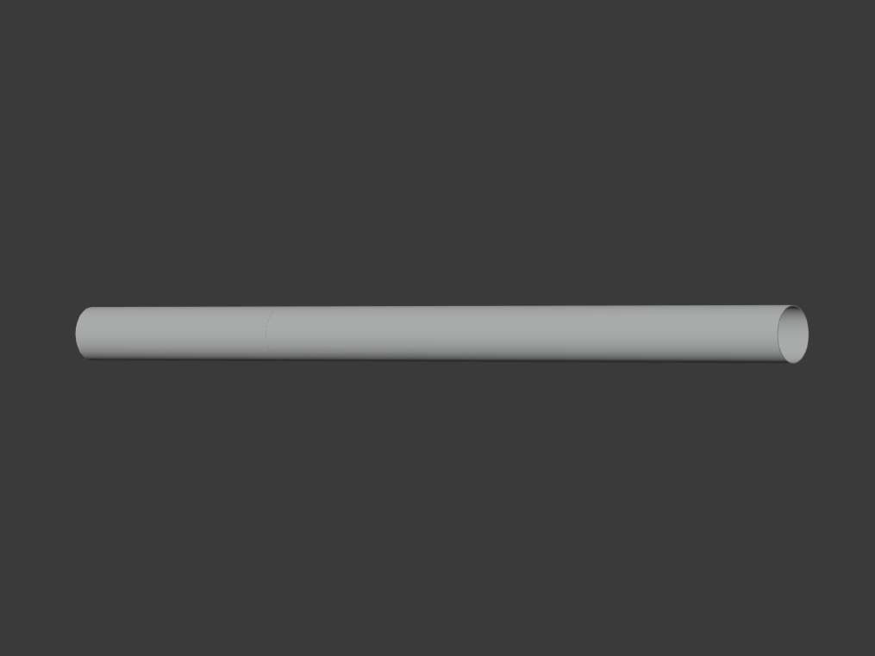
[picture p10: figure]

Figure 5.11: Body Concept model from blender

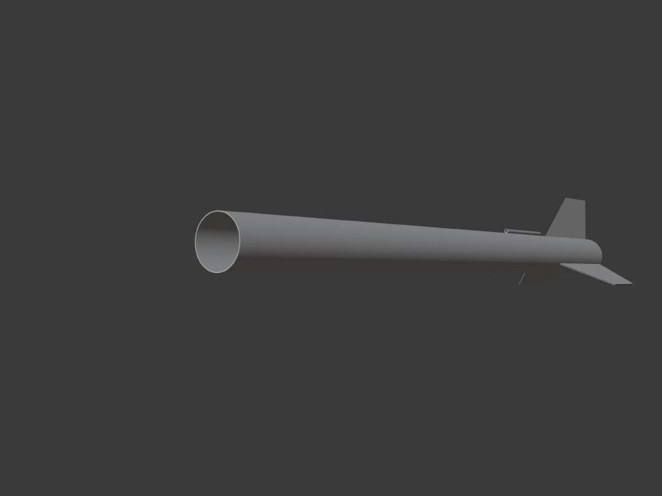
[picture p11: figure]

Figure 5.12: Body with fins concept model from blender

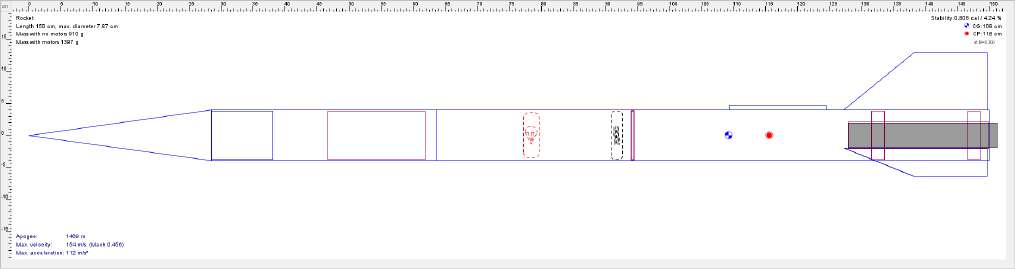
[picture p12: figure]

Figure 5.13: Rocket data from open rocket

The cylindrical form factor was reinforced by an external wrapping of fiberglass cloth impregnated with epoxy, significantly enhancing axial and hoop strength without adding unnecessary mass. This configuration also accommodates internal pressure variations and localized thermal effects generated by the combustion process and ejection charge. Additionally, the chosen material and dimensions allow sufficient electromagnetic transparency for future avionics and telemetry modules, making the structure not only robust but also compatible with data systems necessary for performance validation.

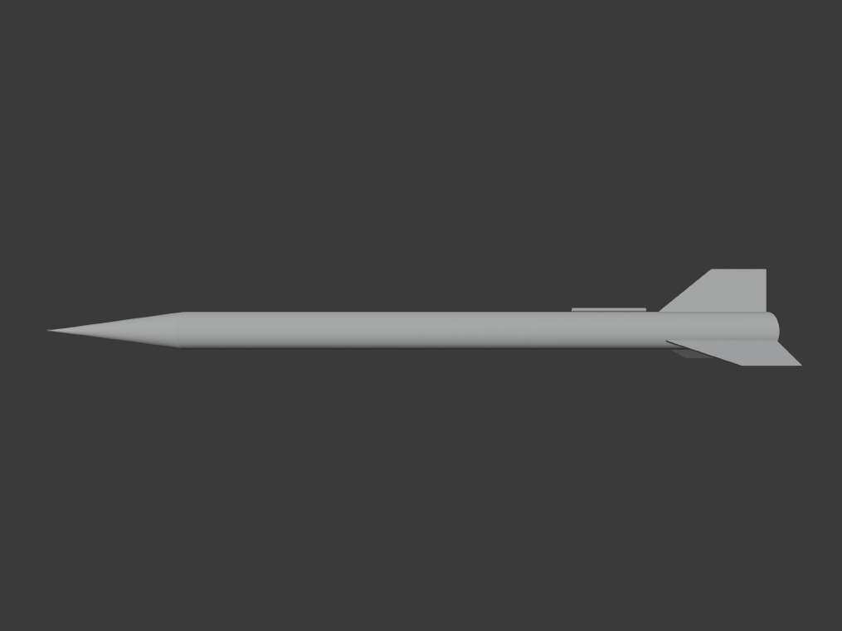
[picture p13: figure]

Figure 5.14: Full rocket Concept model from blender

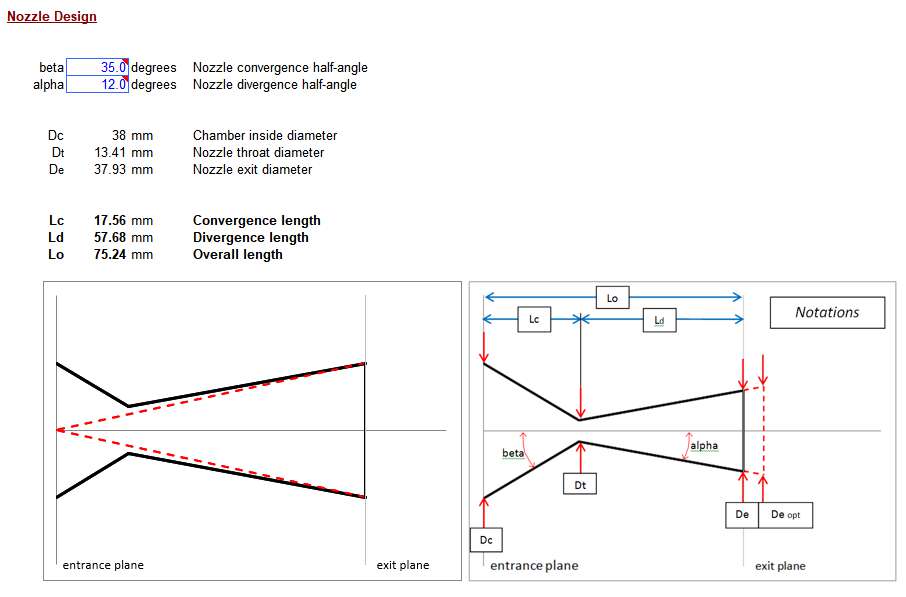
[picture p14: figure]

Figure 5.15: Nozzle data

### 5.1.5 Nozzle Design

The nozzle is a crucial component in the rocket’s propulsion system, responsible for converting the high-pressure, high-temperature combustion gases into a high-speed exhaust jet, thereby producing thrust according to Newton’s third law. In this project, a fixed-geometry converging-diverging (CD) nozzle, commonly known as a de Laval nozzle, was used. The nozzle is designed to be compatible with the characteristics of the KNO3-sugar solid propellant and is fabricated using a heat-resistant epoxy-clay composite to withstand thermal and mechanical stresses.

The primary parameters considered in the nozzle design include the throat diameter, exit diameter, expansion ratio, and material selection. The throat diameter was chosen based on an iterative balance between chamber pressure, burn rate of the propellant, and desired thrust. The exit diameter was optimized for near-atmospheric conditions to maximize exhaust velocity. The design process involves applying the following key formulae:

F = ˙mve + (pe − pa)Ae (Thrust equation)

ve =

### vuut

2γ
γ − 1
- RTc ·

1 −

pe
pc

γ−1
γ

!
(Exhaust velocity)

At =

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
γ + 1 γ+1
2(γ−1)
(Throat area)

ϵ =

Ae
At

(Nozzle expansion ratio)

Where:

- F is the thrust (N)
- m˙ is the mass flow rate (kg/s)
- ve is the exhaust velocity (m/s)
- pe, pa are the exit and atmospheric pressures respectively (Pa)
- Ae, At are the exit and throat areas respectively (m²
)
- γ is the specific heat ratio of the exhaust gases (typically 1.2–1.3 for sugar propellant)
- R is the specific gas constant (J/kg·K)
- Tc is the chamber temperature (K)
- pc is the chamber pressure (Pa)

The nozzle was 3D-printed initially for prototype validation and later fabricated using a molded composite of clay and high-temperature epoxy for the final build. The converging section smoothly guides the gas toward the throat, minimizing flow separation. The diverging section expands the gases to supersonic speeds, increasing the specific impulse. A small graphite insert was added to the throat region to prolong its life during the burn.

By carefully matching the nozzle’s geometry to the combustion characteristics of the propellant, a stable and efficient thrust profile was achieved. The final nozzle geometry ensures that the thrust-to-weight ratio exceeds the required minimum for lift-off and contributes to the rocket’s peak altitude performance.

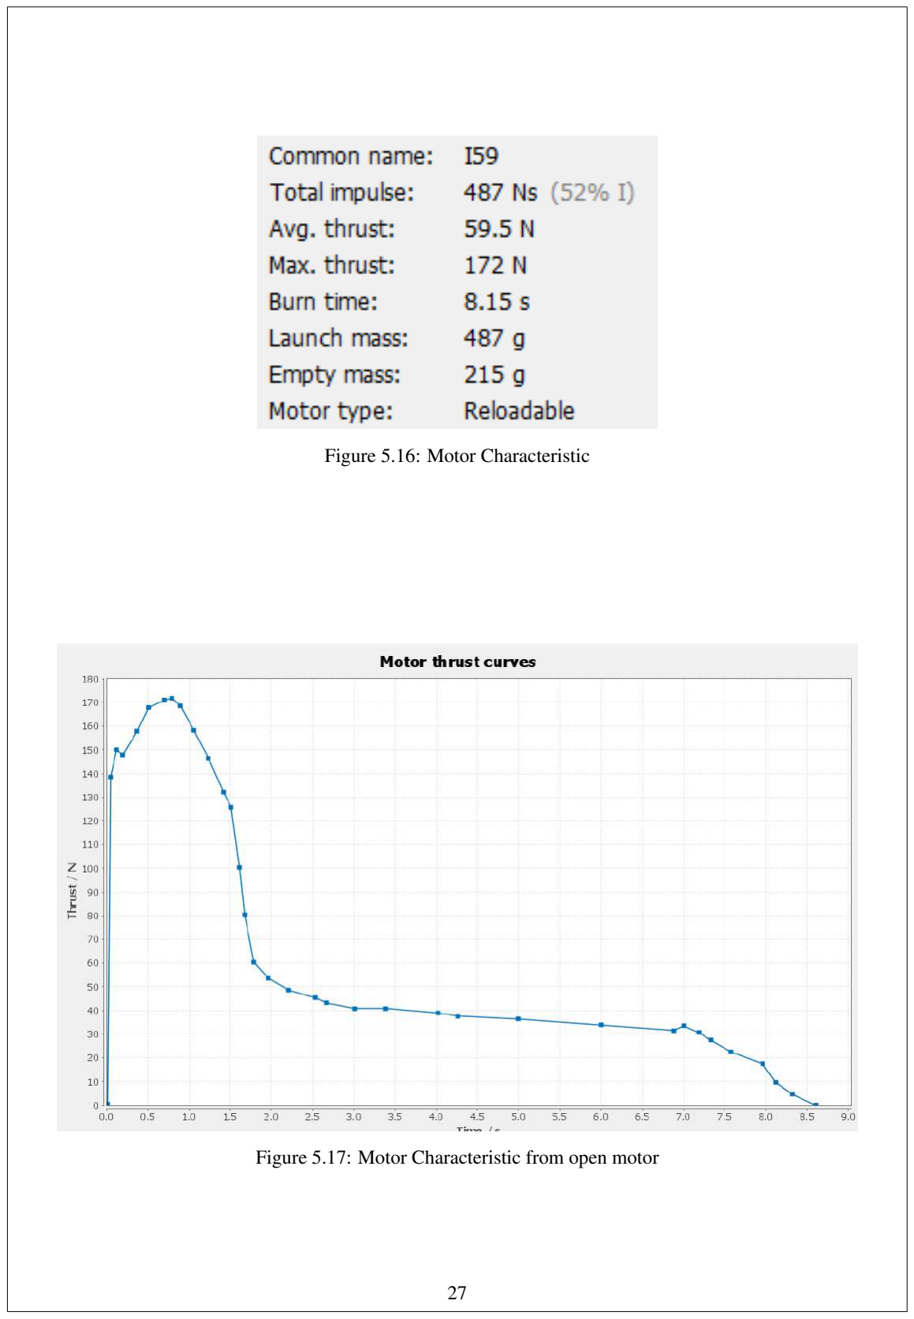
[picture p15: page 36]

Figure 5.16: Motor Characteristic

Figure 5.17: Motor Characteristic from open motor

# CHAPTER 6: Mechatronics and Controls

## 6.1 Electronics

The electronics system in this rocket serves as the central intelligence hub, responsible for sensing, logging, interpreting, and commanding critical flight events. Given the low-cost, self-fabricated nature of this vehicle, the electronics suite was designed with modularity, reliability, and functional redundancy in mind. The entire avionics unit is housed within a dedicated payload bay, safely enclosed and isolated from the motor compartment using kraft phenolic bulkheads and couplers.

At the heart of the system is a microcontroller-based flight computer that interfaces with multiple onboard sensors. These sensors record atmospheric pressure, acceleration, temperature, and altitude in real time. A barometric pressure sensor, paired with an inertial measurement unit (IMU), enables accurate apogee detection through data fusion, reducing false positives due to rapid velocity changes or transient spikes in altitude.

The system architecture supports dual deployment logic—triggering the ejection charges for both drogue and main parachutes. The first charge is fired immediately after apogee is detected, using a small delay charge integrated into the fuel module itself, which pushes the nose cone forward and initiates deployment. The second charge is altitude-dependent and is either handled by the same controller with preset thresholds or, in redundant configurations, by a secondary system triggered via a barometric cutoff. Both igniter circuits are electrically isolated and powered by independent voltage regulators to ensure fail-safe operation.

To ensure data reliability and mission traceability, all flight data is logged to onboard storage—typically a microSD module—and simultaneously transmitted over RF telemetry to a ground station. This dual strategy ensures recovery of flight logs even in case of telemetry failure. The entire system is powered by a compact, rechargeable Li-ion battery pack secured within the avionics bay and protected against overcurrent events.

While advanced commercial systems offer higher resolution and integration, our custom-built avionics emphasize affordability, adaptability, and repairability. The structure allows easy swaps of controller boards, sensor modules, or telemetry units depending on mission profile or component failure—making the electronics bay as modular and scalable as the rest of the vehicle architecture.

## 6.2 Aviation Bay

The avionics bay is designed as a compact, cylindrical payload module that integrates all critical electronics, including flight computers, sensors, telemetry, and power systems. Built from kraft phenolic tubing reinforced for structural stability, the bay is mounted between two circular phenolic bulkheads and reinforced using three stainless steel threaded rods. These rods serve as both the structural spine of the bay and mounting points for internal components, ensuring rigidity and shock resistance throughout flight.

A vertical mounting plate made of lightweight fiberboard or 3D-printed polymer is fixed perpendicular to the rods. This plate supports the central flight computer, barometric pressure sensors, IMU, GPS module, and additional telemetry units. The layout is designed for quick access during ground testing and simplifies future upgrades or module replacements.

Power is supplied by a bank of rechargeable Li-ion batteries securely placed within foam cutouts, positioned to balance the load and maintain CG stability. This configuration also minimizes vibration-induced wear and ensures electrical safety during ignition and ejection events.

The cylindrical shape of the bay not only complements the rocket’s aerodynamic profile but also supports even pressure distribution, minimizing localized stress points. It allows for optimal airflow within the airframe and helps protect delicate electronics from excessive heat and shock during motor ignition and parachute ejection events.

Internally, careful attention has been given to wire routing, isolation of high-current paths (e.g., e-matches), and physical separation of telemetry and sensor wiring to avoid interference. The modular design allows the avionics bay to be removed independently of the coupler or payload sections, easing field servicing and post-flight data retrieval.

This structure, while simple, offers robust performance under the dynamic forces of launch, separation, and recovery, ensuring reliable operation of all electronic subsystems throughout the flight.

## 6.3 Parachute Deployment

The parachute deployment system is a critical safety mechanism designed to enable controlled descent and recovery of the rocket’s main components — the nose cone and body — after motor burnout and apogee. Our system uses a dual-stage ejection process consisting of a delay charge followed by an ejection charge, both initiated electrically through the onboard avionics.

M =

Xmr²
(Moment of Inertia) | (6.1)

Upon motor burnout, the delay charge is ignited, producing a timed interval allowing the rocket to reach apogee and stabilize. After this delay, the ejection charge activates, generating a rapid build-up of pressure inside a sealed compartment between the nose cone and the rocket body. This pressure forces the nose cone to separate cleanly from the main body, deploying the parachute stored within the body tube. The design ensures that while the nose cone detaches to allow airflow and parachute deployment, it remains tethered to the main rocket body via the parachute shroud lines. This tethered configuration guarantees that both sections descend together, reducing the risk of damage from uncontrolled impacts.

KE =

1
2

mv²
| (Kinetic Energy) | (6.2)

q =

1
2
ρV ² | (Dynamic Pressure) | (6.3)

The mechanical coupling between the nose and body is achieved through a retention interface designed to hold firmly during ascent but release reliably under the force generated by the ejection charge. This interface often consists of a shoulder or groove machined into the nose cone base and body tube, ensuring a secure yet releasable joint.

## 6.4 Theoretical and Practical Analysis

The separation and recovery mechanism of the rocket relies on creating a sufficient pressure differential inside a sealed compartment between the nose cone and the forward body tube. This pressure is generated by igniting a pre-measured charge of black powder, which rapidly produces expanding gases. The black powder mass was calculated using the ideal gas law to ensure that the internal pressure reaches approximately 30 psi—enough to overcome the frictional and mechanical resistance of the nose cone without damaging the airframe or avionics bay.

F = ma | (Newton’s Second Law) | (6.4)

s = ut +

1
2
| at²
| (Displacement) | (6.5)

The ignition method is passive and relies on a time-delay fuse embedded into the motor casing. This fuse is ignited by the residual heat of the motor’s combustion and is timed to burn through and ignite the black powder after a delay corresponding to the rocket’s predicted apogee. This ensures parachute deployment occurs only after the rocket slows near the top of its trajectory, preventing premature ejection under high velocity.

hmax =

v

2
2g
(Maximum Altitude) | (6.6)

The ejection charge is housed in a central cavity behind the nose cone and sealed with a light barrier that retains the powder until ignition. Upon ignition, the rapid gas expansion generates a force sufficient to eject the nose cone and deploy the parachute. The parachute system includes a ripstop nylon canopy, elastic shock cord, and nylon shroud lines designed to minimize shock loads on deployment.

tapogee =

v
g
(Time to Apogee) | (6.7)

This mechanical timing system, although simple, proved effective for our single-stage rocket flight profile, eliminating the need for onboard electronics and minimizing points of failure.

## 6.5 Parachute Material and Design

We selected ripstop nylon for the parachute material due to its ideal balance of tensile strength, weight, and durability. The ripstop weave incorporates reinforced threads at regular intervals, which provide excellent tear resistance, critical in the high-stress environment of rapid parachute deployment. Its low density reduces overall payload weight while maintaining structural integrity.

Parachute sizing is derived through energy balance and drag equations, targeting a terminal descent velocity of approximately 3 m/s to prevent impact damage upon landing. The drogue parachute is sized smaller to reduce drift and stabilize the rocket’s descent, while the main parachute provides the majority of the drag force during landing.

The shroud lines of the parachute are attached securely to the rocket body at one end and to the base of the nose cone at the other, allowing both parts to descend together while minimizing oscillations or tangling. This tethering also ensures the nose cone does not become a hazardous projectile postseparation.

## 6.6 System Integration and Safety Considerations

The entire ejection system is integrated into the avionics bay, with redundancies to safeguard against ignition failure or premature deployment. The electronics control both charges, with fail-safe programming and real-time data logging for post-flight analysis.

The sealed volume containing the black powder charge is designed to contain combustion gases and direct the ejection force axially, minimizing lateral forces that could damage the airframe. Additionally, all materials exposed to combustion byproducts are chosen for thermal resistance and minimal outgassing.

Due to supply constraints, 3FG black powder was utilized instead of 4FG. Although 4FG offers a faster and smoother burn, 3FG’s combustion characteristics were successfully compensated for by adjusting the charge mass and optimizing the ignition timing.

# CHAPTER 7: Propulsion

The propulsion system of our rocket is based on a sugar-based solid propellant using Potassium Nitrate KNO3 as the oxidizer and Glucose as the fuel. This class of propellant is widely used in amateur rocketry due to its relatively simple manufacturing process, availability of materials, and safe handling characteristics compared to composite propellants.

The fuel was prepared by finely grinding both KNO3 and glucose into powder form to ensure uniform particle distribution. These powders were mixed in a weight ratio of approximately 65:35 and then slowly heated over a temperature-controlled hot plate. As the glucose melted (around 146°C), it began to encapsulate the KNO3 particles, forming a thick slurry. Heating was carefully maintained below 160°C to avoid thermal decomposition or auto-ignition. Once a uniform, caramel-like consistency was achieved, the hot mixture was poured into cylindrical molds lined with insulation material and allowed to cool and solidify, forming a single fuel grain.

Upon ignition, this propellant undergoes a redox reaction, producing large volumes of hot gases. A simplified combustion reaction is given below:

C6H12O6 + 6 KNO3 −−→ 6 CO2 + 6 H2O + 3 N2 + 3 K2CO3 | (7.1)

The combustion generates high-temperature gases such as carbon dioxide, water vapor, and nitrogen, along with potassium carbonate in the solid phase. The pressure developed from this gas expansion inside the combustion chamber is the primary source of thrust. The gas is expelled through a nozzle, which converts thermal and pressure energy into kinetic energy, thus propelling the rocket upward according to Newton’s Third Law of Motion.

The propellant’s performance is characterized by its burn rate and specific impulse. The burn rate is dependent on the internal chamber pressure and follows a power-law relationship, expressed as:

r = aP n
(7.2)

Here, r is the linear burn rate, P is the chamber pressure, a is a proportionality constant, and n is the pressure exponent. For sugar-based propellants, the pressure exponent typically ranges between 0.3 and 0.5. The internal grain design and nozzle diameter were chosen to ensure the chamber pressure remains within the optimal range for steady combustion.

The total impulse generated by the propellant is related to the mass of the propellant and its specific impulse (Isp). Specific impulse is a measure of the efficiency of the propellant and is defined by:

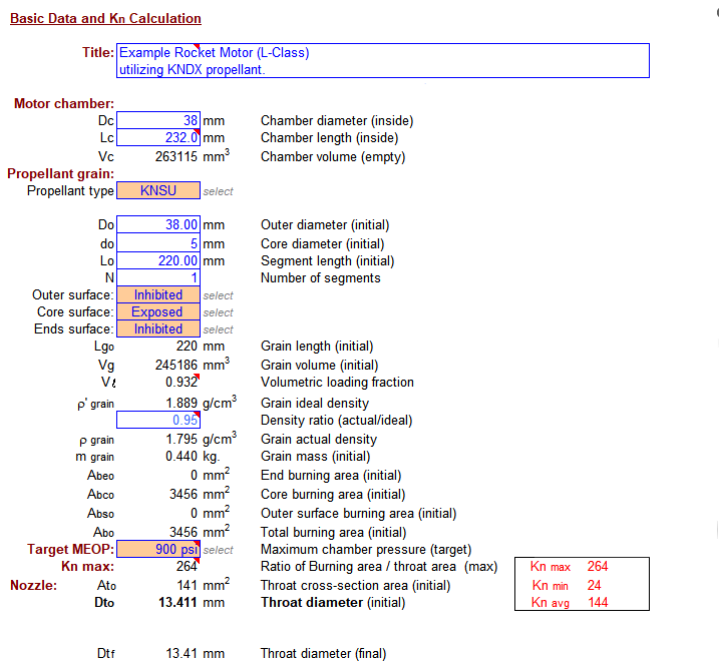
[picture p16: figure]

Figure 7.1: KN calculation

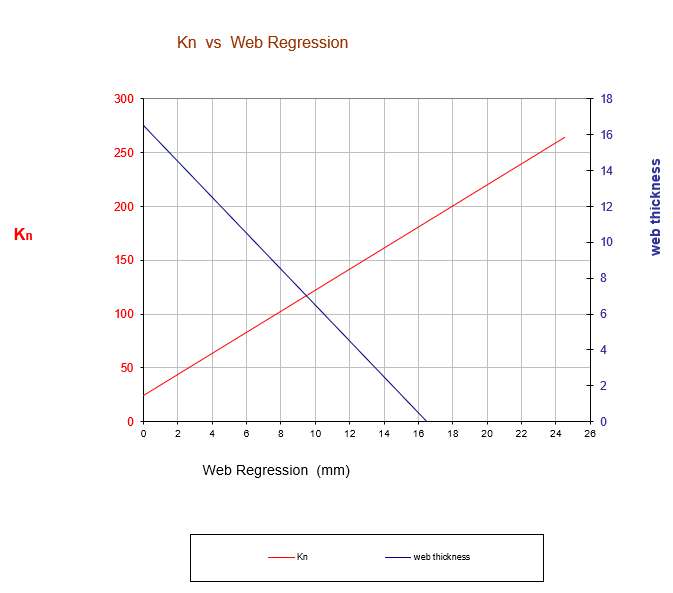
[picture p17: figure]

Figure 7.2: KN vs Web regression

Isp =

Fthrust
mg˙ 0

(7.3)

Where Fthrust is the average thrust, m˙ is the mass flow rate of the expelled gases, and g0 is the standard acceleration due to gravity. For the current propellant, the expected specific impulse ranges from 115 to 130 seconds under sea-level conditions.

The solidified grain was cast into a single cylindrical cavity with a central bore to allow internal burning (end-burner or BATES design). This geometry ensures consistent regression and maintains thrust over the burn duration. The combustion chamber is constructed using a kraft phenolic composite body, selected for its high-temperature tolerance, low weight, and resistance to internal pressure and thermal erosion.

It =

# Z tb

0

F(t) dt | (Total Impulse) | (7.4)

Favg =

It
tb
(Average Thrust) | (7.5)

m˙ =

mpropellant
tb
(Mass Flow Rate) | (7.6)

T/W =

Fmax
mg
(Thrust-to-Weight Ratio) | (7.7)

Ignition is initiated using a nichrome wire that heats upon current application, igniting a small booster charge placed in contact with the main propellant grain. The resulting combustion rapidly builds pressure and begins the primary burn phase.

The exhaust nozzle, designed with a convergent-divergent profile, helps expand the gases and accelerates them to supersonic velocities, thus generating the required thrust. Nozzle erosion is minimized by using a graphite insert in the throat region. The nozzle dimensions were derived based on the expected chamber pressure and desired exit velocity using the isentropic flow relations for compressible gas expansion. This propulsion system offers a low-cost, efficient, and relatively safe solution for high-power rocketry. The use of sugar-based propellant provides adequate thrust to meet our target altitude and flight profile while allowing full control over the burn rate and geometry through fabrication techniques.

# CHAPTER 8: Methodology

The methodology adopted for the development of the high-power model rocket was centered around a balance between theoretical analysis, material experimentation, and iterative prototyping. The project began with extensive research into lightweight structural materials that could withstand the thermal and mechanical stresses generated during launch. Kraft paper laminated with epoxy resin was selected as the primary construction material for the airframe, fins, and internal bulkheads due to its low cost, ease of manufacturing, and favorable strength-to-weight ratio. The phenolic-composite approach allowed the rocket to maintain rigidity while remaining lightweight enough for optimal thrustto-weight performance.

The propulsion system was based on a sugar-based solid propellant composed of potassium nitrate (KNO3) and glucose. This mixture, commonly referred to as a “Rocket candy” propellant, was prepared by carefully heating the oxidizer and fuel in a controlled environment to initiate partial caramelization and achieve a homogeneous melt. The hot slurry was poured into a kraft-based paper motor casing designed to resist internal pressure buildup. The burn characteristics of the propellant were modeled theoretically to estimate the total impulse and thrust curve, assuming complete combustion and ideal nozzle flow. The primary driving mechanism for thrust was the generation of high-temperature gases and pressure buildup in the combustion chamber, which expelled through a converging-diverging nozzle to produce thrust based on Newton’s third law. The relationship between thrust (F), mass flow rate (m˙ ), and exhaust velocity (ve) was given by:

F = ˙mve + (pe − pa)Ae | (8.1)

where pe is the exhaust pressure, pa is ambient pressure, and Ae is the nozzle exit area. The ef-

fective pressure generated from the combustion of the KNO3-glucose mixture was carefully calculated to match the structural limits of the kraft phenolic body tube.

The recovery system relied on a dual-phase parachute deployment mechanism using a delay charge followed by an ejection charge. At apogee, a small quantity of black powder was ignited to pressurize the avionics bay and eject the nose cone. One end of the parachute was attached to the separated nose section, while the other end remained tethered to the rocket body, ensuring both parts descended safely and symmetrically. The charge mass was determined using the ideal gas law, modified to estimate the necessary pressure to overcome coupler friction:

P V = nRT | ⇒ | m =

P V M
RT

(8.2)

where P is the required pressure, V is the volume between the bulkhead and piston, M is the

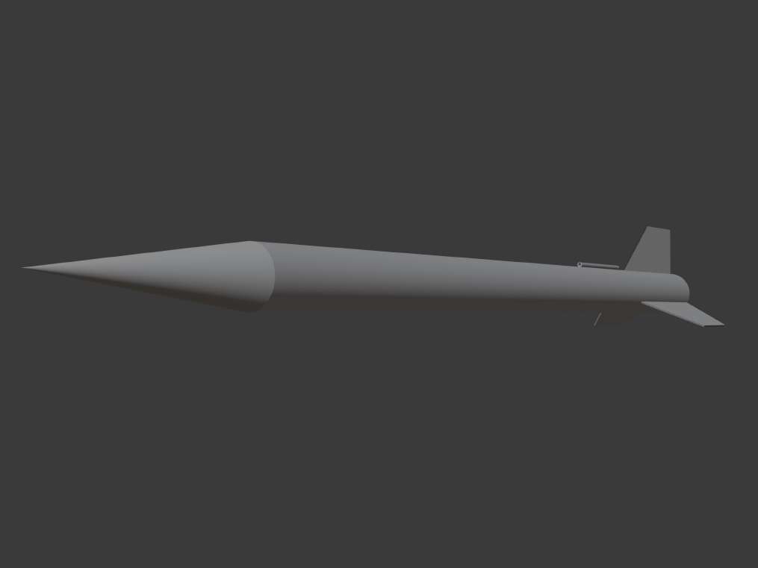
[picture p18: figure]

Figure 8.1: Conept Model from blender

molar mass of the gas, R is the gas constant, and T is the combustion temperature. Based on this, approximately 1.6 grams of black powder was used for reliable separation. The avionics system was assembled within a cylindrical bay using three threaded rods for structural rigidity. A custom PCB was mounted vertically for optimal space utilization, and sensors including barometers, accelerometers, and GPS modules were installed for telemetry and apogee detection. Power was supplied via high-performance lithium cells securely positioned along the inner wall of the bay. All software logic for flight monitoring and deployment control was pre-programmed into the microcontroller before integration.

q = −k

dT
dx | (Fourier’s Law of Heat Conduction) | (8.3)

q = εσT⁴
| (Radiative Heat Flux) | (8.4)

The final configuration was validated through multiple OpenRocket simulations to predict flight stability, apogee, and descent characteristics. Ground tests were conducted to verify structural performance, separation reliability, and burn behavior of the propellant under static conditions. With all systems cross-validated against theoretical expectations, the rocket was cleared for flight trials under controlled launch conditions.

## 8.1 Prototype

The development of a physical prototype was a crucial phase in validating the aerodynamic, structural, and systems integration aspects of the rocket. Serving as both a proof of concept and a learning tool, the prototype demonstrated the feasibility of the proposed design and enabled the team to test key functionalities of subsystems including structural joints, parachute separation, fin alignment, and material selection. More importantly, it allowed for the evaluation of manufacturing accuracy and inter-team coordination across integrated parts.

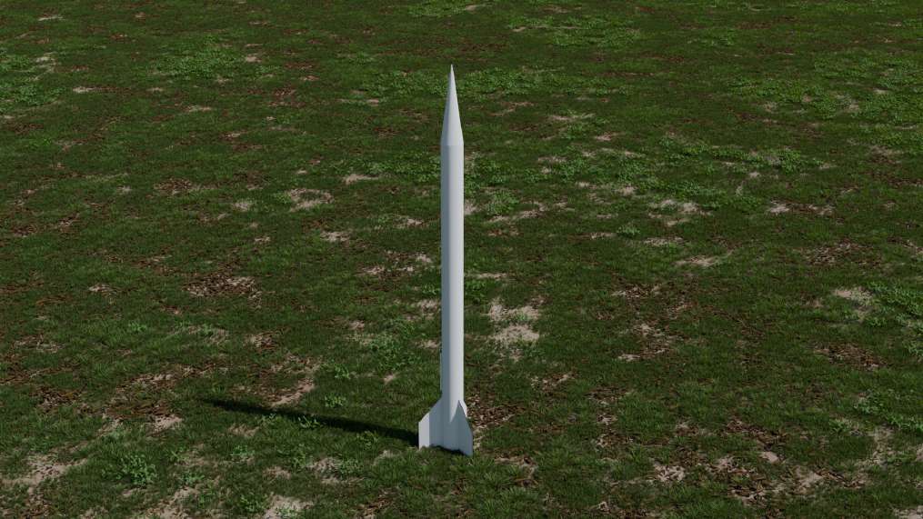
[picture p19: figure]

Figure 8.2: Rocket Art from Blender

The prototype construction involved the fabrication and assembly of the rocket’s major structural components: the nose cone, body tube, fins, and couplers. These components were produced using a combination of kraft phenolic composite materials, fiberglass tubes, and epoxy bonding. The selection of materials was guided by the need for low weight, sufficient mechanical strength, and RF transparency, particularly for ensuring proper telemetry signal propagation. Structural joints were fixed using high-strength epoxy to eliminate the stress concentrations and failure points that are common with mechanical fasteners. The coupling sections and body tube were joined with precision tolerances to ensure aerodynamic smoothness and load distribution during flight.

The constructed prototype closely mirrored the final flight design in terms of dimensions and materials, with only minor exceptions such as the use of fiberglass couplers and commercial phenolic tubes for body structure. These were incorporated to ensure high dimensional precision where critical alignment and sealing were necessary. Through physical testing and visual inspection, the prototype highlighted several practical concerns, such as potential misalignments at joints, epoxy curing inconsistencies, and tolerances that required refinement. These findings were documented to inform

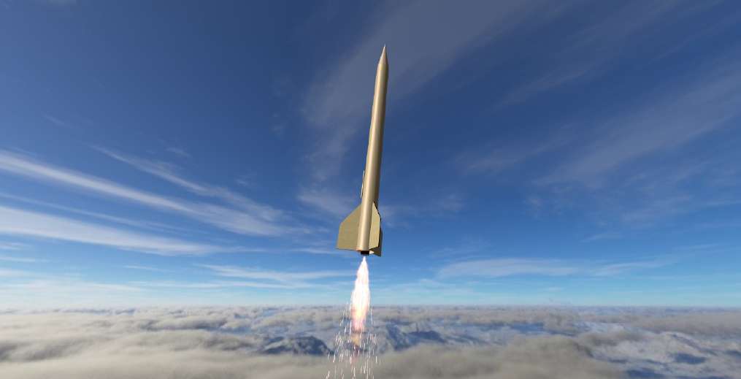
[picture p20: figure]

Figure 8.3: Rocket Concept art from open rocket

adjustments in the final design and assembly procedure. Overall, the prototype served its intended role effectively by bridging the gap between digital design and physical realization. It enabled early detection of design flaws, improved confidence in structural durability, and validated the team’s capacity for precision manufacturing and system-level integration, thereby laying a robust foundation for the final flight model.

### 8.1.1 Manufacturing and Fabrication

Nose cone

A key innovation in our rocket’s construction was the development of a custom composite material used for fabricating the nose cone. This material was created by combining layers of kraft paper with a carefully formulated epoxy resin. The objective was to achieve a material that exhibits high strength-to-weight ratio, structural rigidity, and aerodynamic smoothness—characteristics traditionally associated with glass or carbon fiber composites, but at a significantly lower cost.

The manufacturing process began by cutting kraft paper into long, narrow strips, which were then impregnated with a low-viscosity epoxy resin. This resin was chosen for its deep penetration capability and strong adhesive bonding once cured. Each resin-soaked strip was wound around a rotating conical mandrel to form the nose cone’s shape. The winding was done with care to maintain consistent tension and avoid air bubbles between the layers, ensuring uniform thickness and strength throughout the structure.

As the layers accumulated, the resin began to gel and hold the form, gradually forming a rigid shell. The part was then allowed to cure at ambient temperature for several hours, followed by a postcuring phase under moderate heat to enhance cross-linking within the epoxy matrix. Over time, the

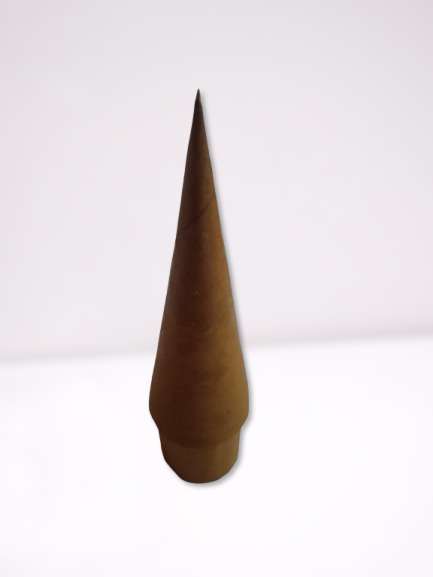
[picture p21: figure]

Figure 8.4: Nose

composite hardened into a structure that closely mimicked the mechanical behavior of traditional fiberreinforced materials. This behavior has been supported in literature that shows kraft paper, when fully saturated with epoxy and layered strategically, achieves performance metrics comparable to earlygeneration composite laminates, particularly in applications involving moderate structural loads and aerodynamic shaping.

Once cured, the nose cone was carefully sanded and finished to improve its aerodynamic profile and ensure a smooth surface finish. The final result was a durable, lightweight, and cost-effective composite nose cone with excellent impact resistance and dimensional stability. This method not only allowed for rapid prototyping and iterative testing but also opened the possibility of using sustainable and widely available materials in aerospace-style fabrication.

The successful implementation of this process demonstrates the viability of low-cost composite manufacturing using kraft paper and epoxy, especially in educational and experimental rocketry where budget and material access are constrained. This approach also aligns with existing research in sustainable composites, where lignocellulosic fibers and paper-based materials are gaining attention as viable alternatives to synthetic fibers in low-to-medium performance applications.

Body

The main body of the rocket was constructed using a kraft paper–based phenolic composite that we custom-fabricated to achieve a high strength-to-weight ratio while maintaining a cost-effective and accessible manufacturing process. The fundamental goal behind this approach was to replicate the properties of traditional phenolic and fiberglass tubing using readily available materials and minimal tooling, while ensuring the body maintained structural rigidity under aerodynamic and internal pressure loads.

To begin fabrication, a rotating mandrel setup was assembled to serve as a support for the body tube during the lay-up and curing phases. This involved using a steel pipe with a diameter smaller than the intended internal diameter of the body tube. Circular end plates were crafted from plywood and precisely sanded to match both the outer diameter of the steel mandrel and the inner diameter of the kraft composite tube. Once inserted into both ends of the tube, the mandrel provided a stable axis around which the material could be wound and rotated during lamination. The core of the body tube

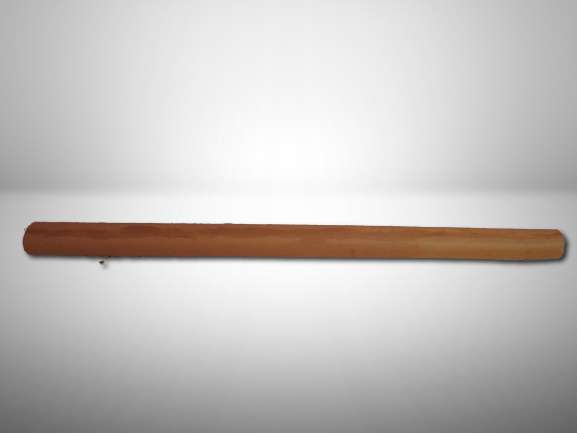
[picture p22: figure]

Figure 8.5: Body of the Prototype

structure was constructed by spirally winding strips of kraft paper that were fully impregnated with a low-viscosity epoxy resin. These strips were tightly wrapped under uniform tension along the length of the mandrel to build up the desired wall thickness. This spiral winding technique helped distribute mechanical loads efficiently along the axis of the rocket. After a sufficient number of layers had been applied, the full layup was allowed to settle and begin curing. Excess resin that surfaced during winding was smoothed out to prevent inconsistencies and surface defects.

To enhance the composite’s structural performance, a final outer layer of epoxy-saturated kraft paper was laid longitudinally, followed by wrapping the body tube with clear mylar film. This film served both to compress the laminate during curing and to create a smooth finish by squeezing out excess resin and eliminating air bubbles. This compression method is essential in resin-based composites to prevent delamination and voids that could compromise the structural integrity during launch.

The curing process occurred in two stages. Initially, the assembly was left at room temperature to allow the epoxy to gel and set. Once the structure became semi-rigid, it was post-cured under a gentle heat source to accelerate cross-linking within the resin matrix, resulting in a significantly more rigid and impact-resistant tube. Once fully cured, the body tube was demolded from the mandrel and trimmed to exact length using a precision band saw.

The final result was a lightweight, durable body tube that rivals traditional phenolic and fiberglass components in terms of performance. The kraft-phenolic composite body proved strong enough to endure flight stresses, while also being lighter and more affordable than its commercial counterparts. This method also enabled rapid prototyping and allowed for adjustments during the early development phase, which would be highly beneficial for future iterative designs.

Fins

The rocket’s fins were crucial for ensuring aerodynamic stability throughout flight and were manufactured using the same kraft paper–epoxy composite method employed in the construction of the body tube. The dimensions and profile of the fins were derived directly from simulations conducted in OpenRocket software, which allowed precise modeling of the center of pressure and overall aerodynamic behavior. Based on these simulations, a three-fin configuration was selected for optimal balance between stability and drag. To fabricate the fins, multiple sheets of kraft paper were first cut into rough fin outlines, slightly oversized to allow for trimming after curing. Each layer was impregnated with a low-viscosity epoxy resin and stacked to the desired thickness, ensuring uniform resin distribution throughout the layup. The layers were pressed flat between two acrylic sheets wrapped in polyethylene to prevent adhesion, and then clamped under moderate pressure to allow the composite to cure into a rigid plate. This pressure curing method helped minimize trapped air and ensured strong interlayer bonding.

Once cured, the flat laminated sheets were removed and precisely cut into their final fin shapes using a fine-tooth band saw. Edges were sanded to achieve smooth aerodynamic profiles, with a slight bevel applied to the leading and trailing edges to reduce drag during flight. A slot-mounting configuration was chosen to provide strong mechanical engagement between the fins and the rocket body. The aft end of the body tube was pre-slotted before final curing, allowing the fin roots to be inserted directly into the wall of the tube.

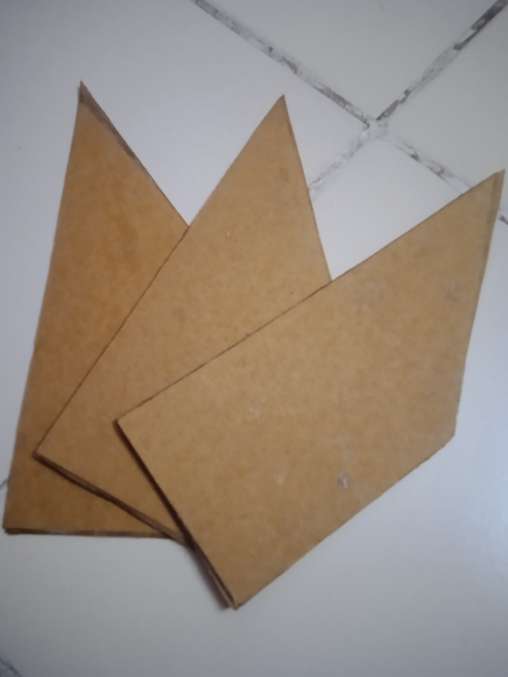
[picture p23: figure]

Figure 8.6: Fins

Each fin was bonded into its respective slot using a high-strength epoxy adhesive. Care was taken to ensure precise angular spacing of 120 degrees between each fin, maintaining symmetry and aerodynamic consistency. After the fins were secured in place, internal fillets of thickened epoxy were applied at the root-tube junctions to enhance load distribution and prevent delamination during high-G phases of launch and recovery. Finally, external surface fillets were added for additional mechanical support and aerodynamic smoothing.

The resulting fin assembly, though constructed from lightweight materials, exhibited excellent rigidity and strength. By integrating kraft paper–epoxy laminates, we achieved a cost-effective yet structurally robust solution, comparable to commercial-grade fiberglass fins. This fabrication method also allows for easy replication or modification in future design iterations.

Fuel Container and Nozzle Fabrication

The fuel container for the propulsion system was fabricated using the same kraft paper and epoxy resin-based composite technique employed for the body and nose cone. This approach not only maintained material consistency and reduced cost, but also yielded a container that was lightweight, durable, and structurally robust. The kraft-phenolic composite provides good thermal insulation and moderate resistance to the internal pressures and thermal loads generated during combustion, making it suitable for short-duration high-impulse flights.

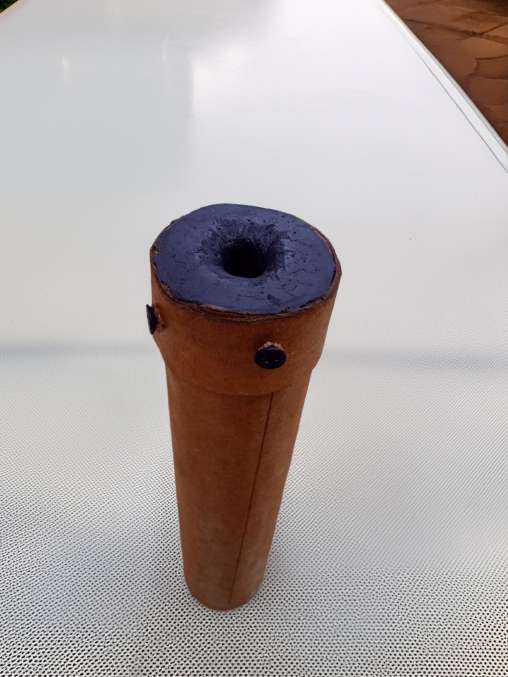
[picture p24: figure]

Figure 8.7: Motor along with the nozzle

The fuel container was cylindrical in shape, matched precisely to the grain diameter of the solid propellant. The composite layup involved rolling multiple layers of kraft paper around a metal mandrel, with each layer impregnated with epoxy resin to ensure bonding and structural integrity. After achieving the required wall thickness, the entire assembly was allowed to cure under compression to eliminate air gaps and promote resin penetration. Once cured, the container formed a rigid and stable casing for casting the sugar-based solid fuel directly inside.

Particular attention was given to the fabrication of the nozzle, as it is a critical component in maximizing thrust and directing exhaust flow. The nozzle was fabricated using the same kraft-phenolic composite material, but with reinforced bonding and additional layers at the throat and exit sections to enhance heat resistance and withstand the extreme mechanical stresses during combustion. A mold was created to form the precise shape of the nozzle, based on the principles of a de Laval nozzle design. The de Laval nozzle, characterized by its converging-diverging shape, was selected for its ability to accelerate combustion gases from subsonic to supersonic speeds, thereby maximizing the thrust output. The nozzle begins with a converging section that narrows down to a throat, where the flow reaches Mach 1 (choked flow). Following this, a diverging section allows the high-temperature, high-pressure gases to expand, converting thermal energy into kinetic energy, and accelerating the exhaust to supersonic velocities.

The de Laval nozzle’s effectiveness is governed by the area ratio between the exit and throat, as well as by the combustion chamber pressure and temperature. According to rocket propulsion theory, the ideal exit velocity ve of the exhaust can be calculated by:

ve =

### vuut

2γ
γ − 1

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
Where:

- γ is the ratio of specific heats (for combustion gases, typically around 1.2–1.3),
- R is the universal gas constant,
- Tc is the combustion chamber temperature,
- M is the molar mass of the exhaust gases,
- pc and pe are chamber and exit pressures respectively.

Care was taken to ensure the nozzle throat diameter and expansion ratio matched the expected operating parameters for the sugar-based fuel, thereby optimizing the specific impulse and thrust coefficient. The nozzle’s inner surface was treated with a thin coating of heat-resistant ceramic-like epoxy for additional thermal protection during the peak thrust phase.

This handmade composite nozzle has proven to be both lightweight and capable of handling the thermal and mechanical loads required for low-altitude solid propulsion, while demonstrating the practical viability of using affordable, accessible materials in student-led rocketry.

### 8.1.2 Propulsion Preparation

The propulsion system for this rocket utilized a homemade solid composite propellant based on a potassium nitrate (KNO3) and sugar mixture, a formulation commonly known in amateur rocketry as ”rocket candy.” This type of propellant is classified as a composite sugar-based solid fuel and is widely documented for its simplicity, safety (compared to other high-energy propellants), and relatively high performance for low-cost propulsion systems. The oxidizer-to-fuel ratio selected for this project was 70:30 by mass, where potassium nitrate acted as the oxidizer and glucose (alternatively sucrose) as the fuel.

The preparation process was carried out in a controlled environment to ensure safety and consistency in propellant quality. The KNO3 and glucose powders were first finely ground and sieved separately to ensure homogeneity and enhance the reactivity during the heating phase. These were then thoroughly dry-mixed in the 70:30 ratio using a stainless-steel bowl to avoid contamination and static discharge risks. A double-boiler system was used to heat the mixture gently, keeping the temperature below 150°C to prevent premature decomposition or ignition. During this phase, the mixture gradually transitioned from a dry powder into a viscous caramel-like fluid. This is the caramelization process of sugar, which allows the molten sugar to encapsulate the oxidizer particles, forming a homogenous energetic material.

Heating was continued until the mixture took on a golden-brown appearance and reached a thick, pourable consistency—indicative of proper caramelization and integration of oxidizer within the fuel matrix. Care was taken to stir the mixture continuously to prevent local overheating, charring, or uneven distribution of oxidizer. Once the desired consistency and coloration were achieved, the hot propellant was immediately poured into pre-fabricated cylindrical fuel casings made using the kraft-phenolic composite technique. These casings provided both containment and insulation for the propellant during storage and combustion.

After casting, a central perforation was made axially along the length of the propellant grain using a metal rod while the material was still malleable. This perforation follows a core-burn geometry, enhancing the initial surface area exposed to combustion and providing a more uniform burn rate and higher thrust generation during flight. The core-burn configuration is well-documented to improve the pressure curve characteristics of sugar-based motors, as it allows the surface area to remain approximately constant throughout much of the burn cycle.

Once cooled, the solidified propellant took on a hard, glassy consistency, indicating successful curing. These fuel grains were then stored in sealed containers to prevent moisture absorption, which could degrade both the mechanical and energetic properties of the propellant.

In addition to its primary role as a combustion chamber, the fuel container also houses a delay charge and an ejection charge system essential for the rocket’s recovery sequence. Positioned aft of the main propellant grain, a dedicated cavity was included during the casting process to accommodate the delay composition. This delay charge, typically made of a slower-burning mixture of oxidizer and fuel (in a reduced reactivity formulation), burns at a controlled rate after the main propellant has fully combusted. It acts as a timing mechanism, ensuring that the parachute deployment occurs only after the rocket reaches its apogee. Once the delay charge is consumed, it ignites the ejection charge—a small but energetic black powder-like mixture—that generates a rapid pressure buildup. This sudden pressure is directed toward the recovery bay, effectively ejecting the nose cone or a coupler, and pushing the parachute assembly out of the body tube. To ensure effectiveness, this mechanism was pressure-tested using sealed-end trials, and the container was structurally reinforced around the recovery bay interface with extra layers of kraft-epoxy laminate. This integration ensures that the recovery mechanism functions reliably without compromising the structural or thermal integrity of the propulsion system.

This method of propulsion preparation has been validated by several amateur rocketry groups and research papers. Studies such as those by Humble, Henry et al. (“Space Propulsion Analysis and Design”) and in experimental rocketry forums and journals show that a KNO3-sugar ratio around 65–75% oxidizer yields optimal specific impulse (Isp) values in the range of 80–120 seconds, depending on geometry and chamber pressure. While this is lower than composite AP-based motors, the ease of manufacturing and safety profile make it ideal for student-led and low-budget aerospace projects.

This propellant formulation and casting process were selected for its balance of performance, cost, and ease of handling, with rigorous attention paid to safe heating and uniform casting. These efforts contributed to the reliable operation of the propulsion system during both static and flight tests, demonstrating the effectiveness of sugar-based propellants in low-altitude high-power rocketry.
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

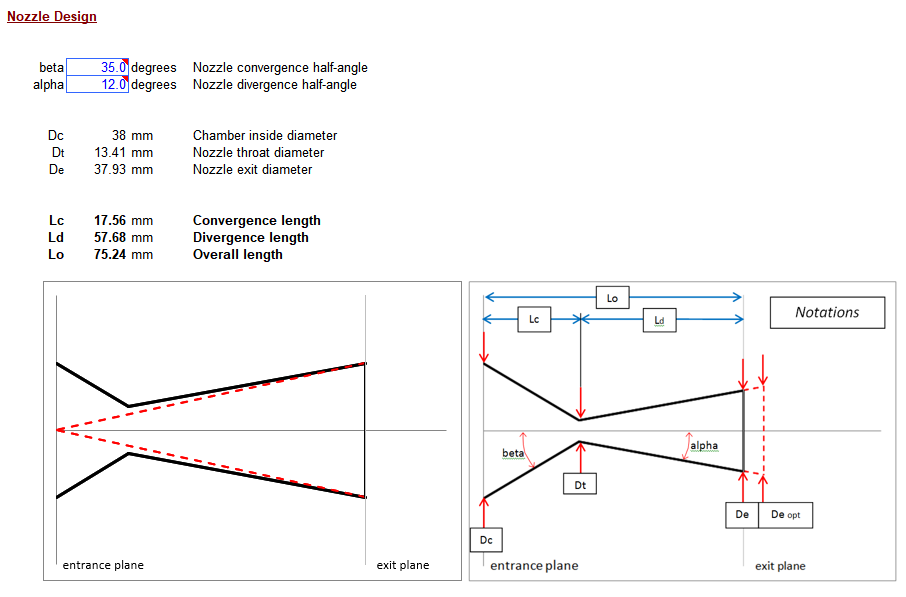
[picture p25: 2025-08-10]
SRM/Nozzle Design.png

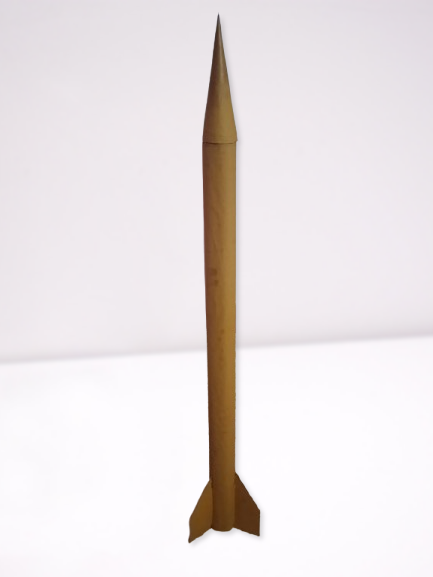
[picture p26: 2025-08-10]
Images/WhatsApp_Image_2025-05-24_at_05.33.46_5ff534d3-removebg-preview.png

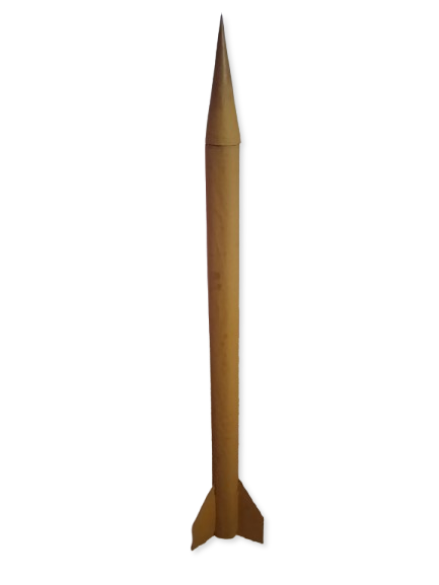
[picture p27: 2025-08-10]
Images/download.png

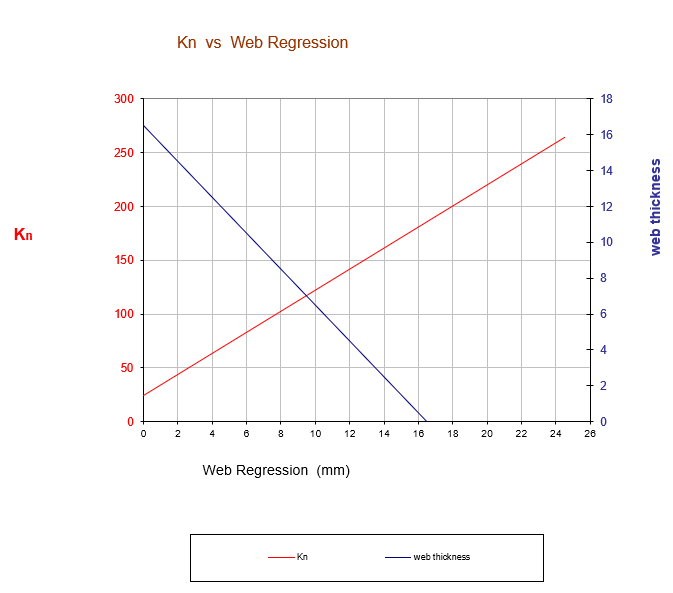
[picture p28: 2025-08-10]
SRM/KN vs Web regression.png

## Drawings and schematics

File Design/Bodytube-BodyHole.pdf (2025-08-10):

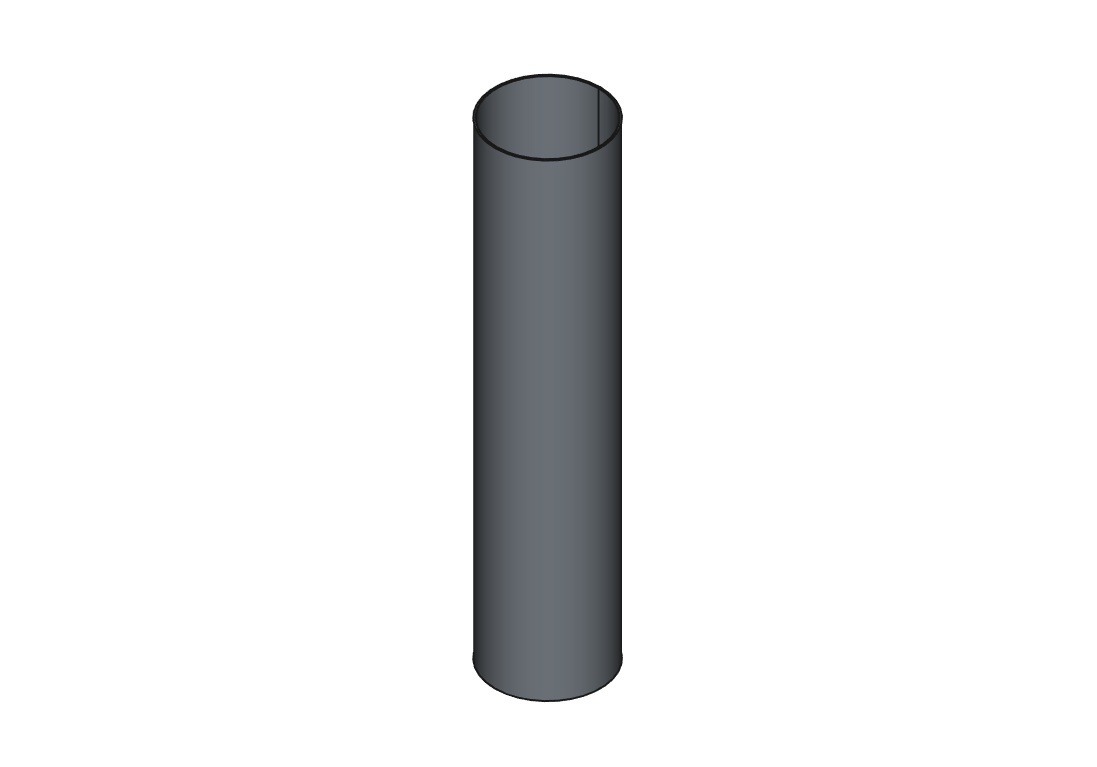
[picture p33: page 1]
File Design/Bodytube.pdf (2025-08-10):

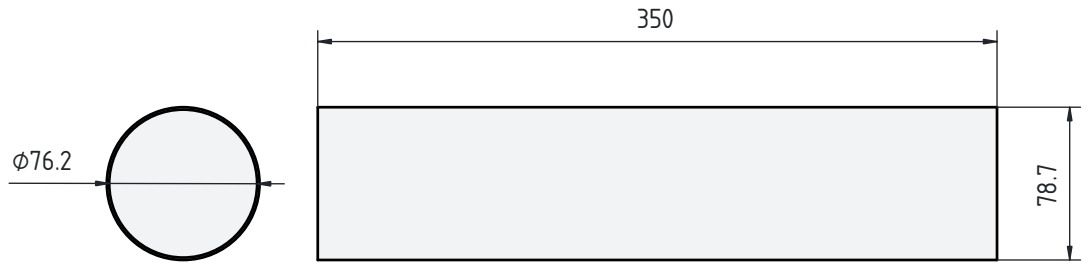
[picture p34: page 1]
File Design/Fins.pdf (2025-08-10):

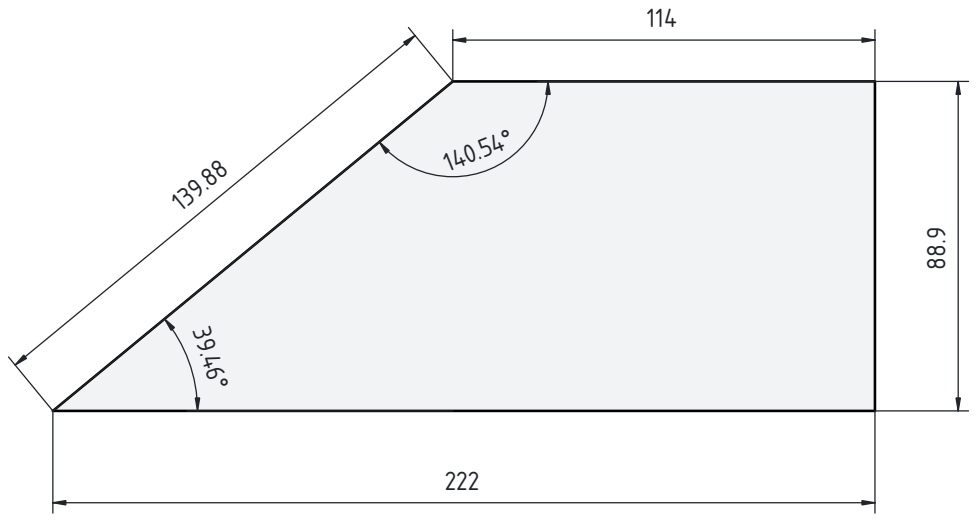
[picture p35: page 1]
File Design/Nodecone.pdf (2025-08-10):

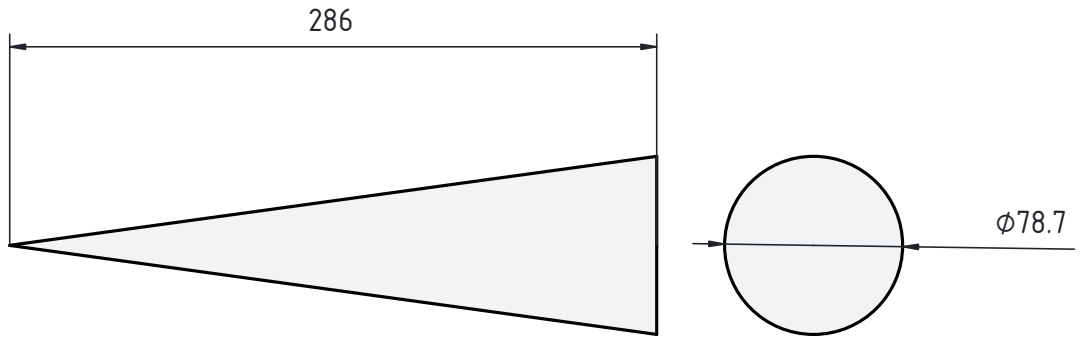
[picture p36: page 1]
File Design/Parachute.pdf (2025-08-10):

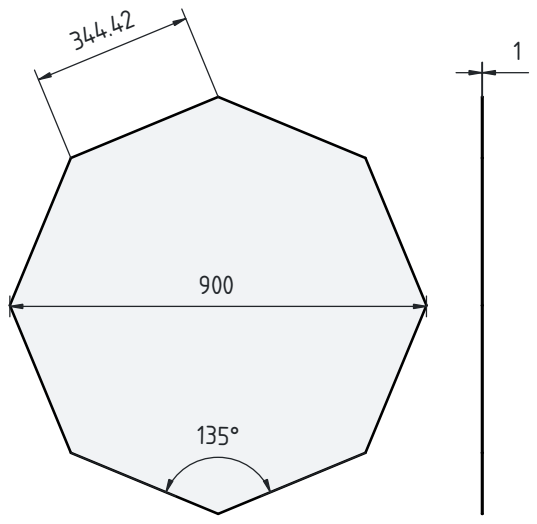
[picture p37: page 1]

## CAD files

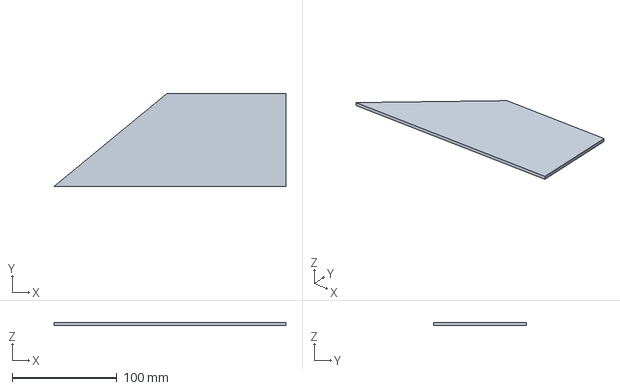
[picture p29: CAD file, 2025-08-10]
Design/Fins.FCStd
222.0 x 88.9 x 3.18 mm

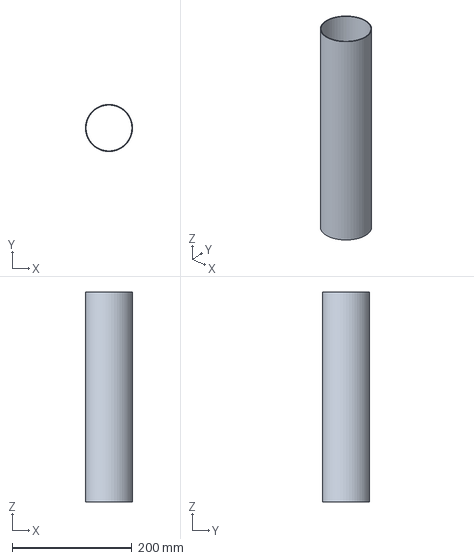
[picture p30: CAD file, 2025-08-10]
Design/BodytubeDWG.FCStd
78.6 x 78.7 x 350.0 mm

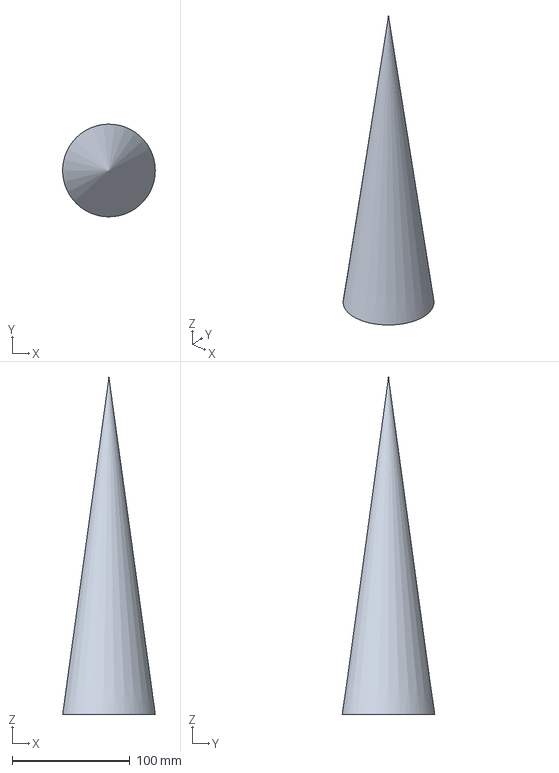
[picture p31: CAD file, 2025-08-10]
Design/Nosecone.FCStd
78.6 x 78.7 x 286.0 mm

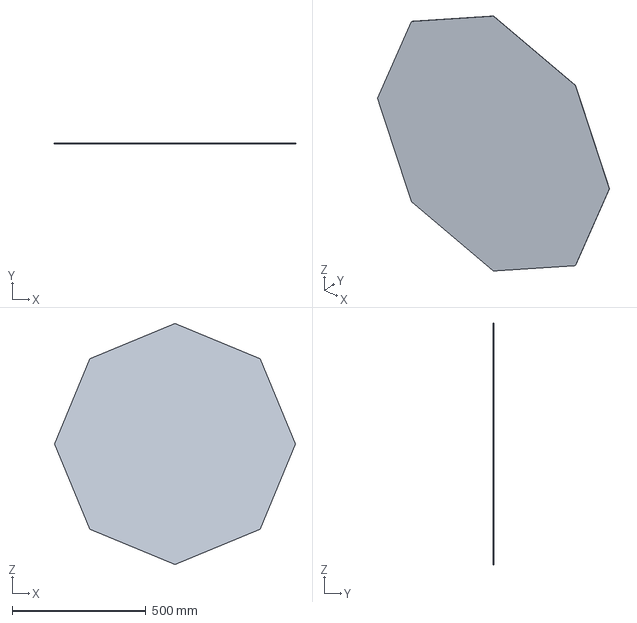
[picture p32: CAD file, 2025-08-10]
Design/Parachute.FCStd
900.0 x 1.00 x 900.0 mm

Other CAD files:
Design/FinsDWG.FCStd
Design/Bodytube.FCStd
Design/NoseconeDWG.FCStd
Rocket file.blend
